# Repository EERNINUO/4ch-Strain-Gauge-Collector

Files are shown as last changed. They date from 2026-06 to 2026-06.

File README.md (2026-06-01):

<div align="center">

<!-- Assisted-by: DeepSeek - 文档框架 -->

# 4ch-Strain-Gauge-Collector

创新创业实践课程设计 E4 选题 – 4通道应变信号同步采集模块  
基于 STM32G473，内置 ADC + 高速 SRAM 缓冲 + USB 触发同步

<p align="center">
  <a href="https://github.com/EERNINUO/ArbWave30" style="margin: 2px;">
    
  </a>
  <a href="https://github.com/EERNINUO/ArbWave30" style="margin: 2px;">
    
  </a>
  <br/>
  <a href="https://raw.githubusercontent.com/EERNINUO/ArbWave30/main/LICENSE" style="margin: 2px;">
    
  </a>
  <a href="https://raw.githubusercontent.com/EERNINUO/ArbWave30/main/LICENSE" style="margin: 2px;">
    
  </a>
  <a href="https://raw.githubusercontent.com/EERNINUO/ArbWave30/main/LICENSE" style="margin: 2px;">
    
  </a>
</p>

</div>

---

## 📌 项目简介

本项目为《创新创业实践课程》课程 E4 选题的硬件与固件设计成果。  
设计基于 **STM32G473**（Arm Cortex-M4F）实现了 **4 通道应变信号同步采集**，支持外部事件触发、高速数据缓存（SRAM）及非易失参数存储（QSPI Flash），并通过 USB/串口实现与 PC 的命令交互与多模块同步。

设计周期：2 周（原理图 + PCB + 仿真 + 文档 + CubeMX工程，无实物焊接与固件代码）  
参考原型：NI‑9237 应变/桥输入模块

**核心指标**：
- 4 通道差分输入（±2.5V，共模 1.65V）
- 12 位内置 ADC，支持硬件过采样
- 4 阶有源低通滤波器（100kHz / 200kHz 可选）
- 最多 4 片 IS61WV204816BLL 高速 SRAM（2M×16bit）
- QSPI Flash 存储固件及标定参数
- USB 2.0 FS + 可线与串口（多模块同步触发）

## 🎯 主要特性

| 模块 | 特性 |
|---|---|
| **模拟前端** | 仪表放大器 (INA) + 1/4 衰减网络 + 4 阶 Sallen-Key 滤波器，净增益 1 |
| **ADC** | 内置 5 个独立 12 位 ADC，支持差分输入，事件触发同步采样 |
| **触发机制** | 片上比较器 (CMP) 整形外部触发信号，直接路由到定时器，响应延迟 < 1µs |
| **数据缓存** | FMC 总线扩展 SRAM（1~4 片），支持连续高速采集 |
| **存储** | QSPI Flash 用于程序 XIP 及标定参数掉电保存 |
| **通信** | USB CDC 虚拟串口 / 可线与硬件串口，支持多机同步 |

---

## 🖥️ 硬件架构概览

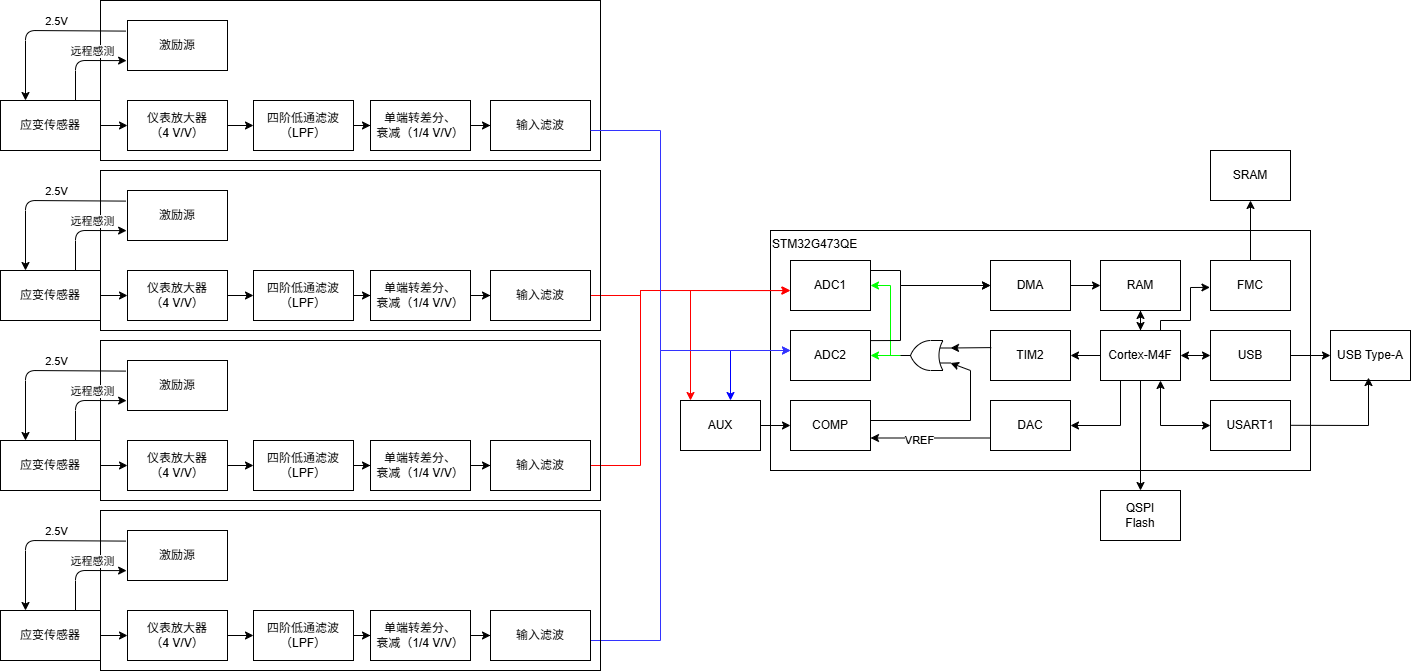
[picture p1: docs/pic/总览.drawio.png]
总览


详细原理框图及模块说明见 [硬件设计文档](docs/硬件设计文档.md)。

## 🛠️ 开发工具与环境

| 用途 | 工具 | 版本 |
|---|---|---|
| 原理图 & PCB |  KiCad | 10.0 |
| 模拟仿真 | LTspice  | 26.0.1 |
| MCU 配置 | STM32CubeMX | 6.13 |
| 代码生成 | Keil MDK | 5.36  |
| 版本管理 | Git + GitHub | - |

## 📁 仓库结构
4ch-Strain-Gauge-Collector/
├── docs/                     # 设计文档  
│   ├── pic/                  # 文档中用到的图片  
│   ├── hardware_design.md    # 硬件设计文档（原理图、PCB、BOM）  
│   └──  LICENSE              # CC BY-SA 4.0   
├── simulation/               # LTspice 仿真文件  
├── firmware/                 # CubeMX工程与生成代码（CubeMX + Keil）  
│   └── STM32G473.ioc         # CubeMX 配置文件  
├── hardware/                 # 硬件设计源文件  
|   ├── E4                    # Kicad 原理图与 PCB 文件  
│   └── LICENSE # CERN-OHL-S-2.0     
├── README.md                 # 项目说明  
└── LICENSE                   # GPL-3.0  

## 📜 许可证
Copyright © 2026 EERNINUO

本项目采用**多许可证策略**，不同部分适用不同许可证：

| 组成部分 | 许可证 |
|---|---|
| 固件 (MCU/FPGA 代码) | [GNU General Public License v3.0](LICENSE) |
| 硬件设计文件 (原理图、PCB、BOM) | [CERN Open Hardware Licence Version 2 - Strongly Reciprocal](hardware/LICENSE) |
| 文档、图片、README | [Creative Commons Attribution-ShareAlike 4.0 International](docs/LICENSE) |

这意味着：
- 你可以自由使用、修改、分享固件代码，但任何衍生代码也必须以 GPL-3.0 开源。
- 你可以基于硬件设计文件制作、分发物理设备，但必须同时开源你对设计文件的修改，并保留署名。
- 你可以复制和修改文档，但必须同样以 CC BY-SA 4.0 分享，并注明原作者。

## 📧 联系方式

如有问题或建议，请在 GitHub Issues 中提出。

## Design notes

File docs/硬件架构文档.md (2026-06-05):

<!------------------------------------------------------------------------
SPDX-License-Identifier: CC-BY-SA-4.0
Copyright (C) 2026 [EERNINUO](https://github.com/EERNINUO)

This work is licensed under the Creative Commons Attribution-ShareAlike 4.0 International License. 
To view a copy of this license, visit http://creativecommons.org/licenses/by-sa/4.0/.
------------------------------------------------------------------------->

<!-- Assisted-by: DeepSeek - 文档框架 -->

# E4 – 硬件架构文档

| 文档编号 | E4-HAD-001 | 版本 | V1.0 |
|---|---|---|---|
| 项目名称 | 创新创业实践课程设计 – E4 应变采集 | 日期 | 2026-05-28 |
| 起草人 | EERNINUO | 状态 | 设计中 |

## 1. 概述
E4 模块基于 **STM32G473** 实现 4 通道应变信号同步采集。外部应变片（半桥配置）输出的微弱差分信号经 **仪表放大器预放大 → 衰减匹配 → 4阶有源低通滤波** 后，送入 MCU 内置 ADC（12位，差分输入）。模块支持 **外部事件触发** 实现同步采集，采集数据通过 **USB 虚拟串口** 上传至 PC，并可选 **QSPI Flash** 存储标定参数、**SRAM** 缓存高速数据。

## 2. 系统框图
总览

## 3. 模块划分与功能定义

### 3.1 模拟前端（AFE）
| 级 | 功能 | 关键要求 | 增益(V/V) | 初步选型 |
|----|---|---|---|---|
| 0 | 应变片 | 激励电压 2.5V，差分输出 mV 级 | - | 350Ω 应变片 + 精密电阻 |
| 1 | 仪表放大器 | 共模抑制比 > 80dB，增益 4 倍 | 4 | INA828 |
| 2 | 4阶有源低通滤波器 | 截止频率 200kHz，巴特沃斯响应 | 1 | Sallen-Key (双二阶级联) |
| 3 | 衰减/单端转差分级 | 1/4 衰减，生成差分信号输入 ADC | 1/4 | 同相/反向放大器 |
| 4 | 输入滤波 | 截止频率 ≈ 1.5MHz，200kHz 衰减 < 0.1dB | 1 | 差分 RC 低通滤波 |
| 5 | ADC | 差分输入，共模 1.25V | ±2.5V（差分） | - | STM32G473 内置 ADC |

### 3.2 数字控制与采集（MCU）
- **型号**：STM32G473QE（128脚）
- **职责**：
  - 配置 2 个独立 ADC 实现 4 通道同步采样（其中 1、4；2、3  通道共用 1 个 ADC，采用双模式）
  - 电平触发采样（通过 MCU 内置比较器），启动采集序列，软件可设计预触发算法
  - 多功能串口触发采集，多机同步
  - 通过 USB（全速）与 PC 通信，实现虚拟串口数据上传
  - QSPI Flash（存储标定参数与程序）
  - 外部 SRAM（IS61WV204816BLL，最多 4 片，本设计选用 1 片）
  - 实现软件增益校准与偏移调零

### 3.3 触发与同步接口
- 电平触发：通过多路选择器选择触发源（CH1 ~ CH4），经 **比较器（内置 CMP）** 整形后触发定时器。
- 支持多模块同步：串口可线与（多模块共享触发总线）。

### 3.4 存储扩展
| 存储类型 | 型号 | 接口 | 容量 | 用途 |
|---|---|---|---|---|
| QSPI Flash | GD25Q32JV | QSPI | 32 Mbit | 程序存储 + 标定参数 |
| SRAM | IS61WV204816BLL | FMC | 2M×16bit | 高速采集数据缓存 |

### 3.5 电源系统
- 输入：DC 5V （DC 2.1mm 电源接口（或 USB 供电））
- 电源架构：
```mermaid
graph TD
    DC_5V -->|AMS1117-3.3V| 3.3V_D
    DC_5V -->|SGM3204| -5V_A
    DC_5V -->|TPS7A4701| 4V_A
    -5V_A -->|TPS7A3301| -4V_A
    4V_A -->|SGM2059| +3.3V_A
    V_REF -->|同相放大器（1/2 V/V）| 1.25V_V_COM[共模参考]
    4V_A -->|SGM2059| EXC_OUT[电桥激励电压（输出）]
    4V_A -->|SGM2059| 2.5V_EXC[2.5V 电桥激励电压]
```
## 4. 关键接口信号定义

| 接口 | 信号 | 方向 | 电平 | 说明 |
|---|---|---|---|---|
| 应变输入（4通道） | CHx_AI+, CHx_AI- | 输入 | 差分 ±2.5V max | 经调理后接 MCU ADC 差分输入 |
| 远程感测 | S+, S- | 输入 | < 2.5V | 可选，补偿线压降 |
| USB | USB_DP, USB_DM | 双向 | 3.3V | USB 全速，虚拟串口 |
| 外部触发 | TX/RX | 双向 | 3.3V/5V | UART 触发输入 |
| 调试接口 | SWDIO, SWCLK | 双向 | 3.3V | ST-Link 调试 |
| 电源输入 | V_IN | 输入 | 5V | DC 5V 电源输入 |

## 5. 物理与机械约束
- PCB 尺寸：110mm × 40mm × 170mm（模盒统一尺寸（内径））
- 连接器布局：USB、DC 2.1mm，开关位于板边、调试排针靠近MCU；4 通道应变输入端子集中布置
- 散热：主要功耗为 LDO，无需额外散热片

## 6. 下一步工作
- 详细原理图设计（仪表放大器、滤波器仿真）
- PCB Layout（重点关注模拟/数字分区、差分对等长）
- MCU CubeMX 配置与代码生成
- 设计报告撰写

## 7. 版本记录
| 版本 | 日期 | 修改内容 | 修改人 |
|---|---|---|---|
| V1.0 | 2026-05-29 | 初始版本 | EERNINUO |

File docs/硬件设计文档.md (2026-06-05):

<!------------------------------------------------------------------------
SPDX-License-Identifier: CC-BY-SA-4.0
Copyright (C) 2026 [EERNINUO](https://github.com/EERNINUO)

This work is licensed under the Creative Commons Attribution-ShareAlike 4.0 International License. 
To view a copy of this license, visit http://creativecommons.org/licenses/by-sa/4.0/.
------------------------------------------------------------------------->

<!-- Assisted-by: DeepSeek - 文档框架 -->

# E4 – 硬件设计文档

| 文档编号 | E4-HDD-001 | 版本 | V1.0 |
| ---| ---| ---- | ---- |
| 项目名称 | 创新创业实践课程设计 – E4 应变采集 | 日期 | 2026-05-28 |
| 起草人 | EERNINUO | 状态 | 设计中 |

## 1. 板卡概述
- 功能定位：4通道应变信号同步采集，经调理后由MCU内置ADC采集，通过USB上传。
- 关键性能指标：
  - 采样率：每通道最大 1 Msps（12位）
  - 输入范围：±10mV（应变满量程）→ 经 4 倍放大 → 1/4 衰减 → ±10mV 进入滤波器 → ADC 输入 ±2.5V
  - 滤波器截止频率：100kHz 或 200kHz（4阶巴特沃斯）
  - 触发响应延迟：< 1μs（硬件触发 + 中断）
- 主要接口：
  - 电源输入：USB Type-B (5V)
  - 数据接口：USB 虚拟串口
  - 调试接口：SWD (4-pin)
  - 外部触发：SMA 接口
  - 4 通道应变输入：端子排或 RJ-50（参考 NI-9237）

## 2. 模块详细设计

### 2.1 输入接口
- **功能描述**：接收来自应变片半桥的差分信号。
- **物理接口**：4 通道输入：RJ-45 接口（8针，4对差分）
- **引脚定义**

| 引脚 | 信号名 | 功能说明 |
|---|---|---|
| 1 | EX+ | 激励电压正 |
| 2 | EX- | 激励电压负 |
| 3 | RS+ | 远程感测电压正 |
| 4 | CH+ | 通道1正输入 |
| 5 | CH- | 通道1负输入 |
| 6 | RS- | 远程感测电压负 |
| 7 | EX- | 激励电压负 |
| 8 | EX+ | 激励电压正 |

### 2.2 模拟前端

#### 2.2.1 仪表放大器（预放大 4 倍）
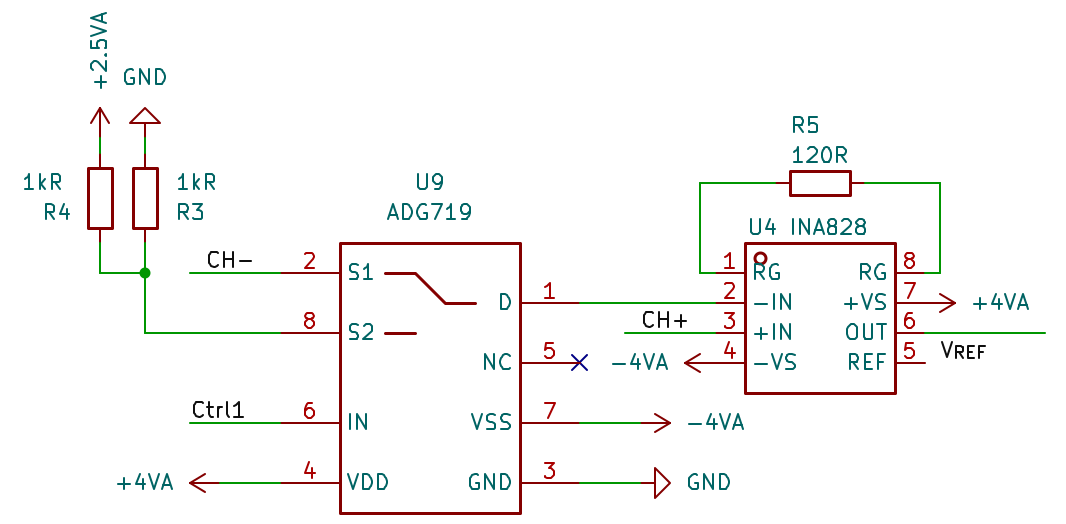
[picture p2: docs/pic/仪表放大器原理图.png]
仪表放大器
- **原理图截图**：
- **功能描述**：将应变片半桥的差分毫伏信号放大 4 倍，提高信噪比。
- **关键器件**：
  
| 器件 | 型号 | 特性 | 选型理由 |
|---|-----|---|---|
| 仪表放大器 | INA828 | 低噪声、高共模抑制比、可进行直流偏置 | 性能满足需求，可进行直流偏置 |
| 模拟开关 | ADG619 | 双电源、高开关速度、低导通电阻、低漏电流 | - |

- **设计计算**：
  - R_G计算：由数据手册可知：$G = 1 + \frac{50 k\Omega}{R_G}$，$G=4$，则 $R_G = \frac{50}{G - 1} \approx 16.7 k\Omega$
  - 输出信号：由数据手册可知 $V_O = G(V_{IN+} - V_{IN-}) + V_{REF}$，则输出电压 $V_O$ 的共模分量 $V_{DC} = V_{REF}$，差模分量 $V_{AC} = G(V_{IN+} - V_{IN-})$
- **接口信号**：
  | 信号名 | 方向 | 连接到 | 备注 |
  |--------|------|--------|------|
  | INA_IN+, INA_IN- | 输入 | 应变半桥输出 | 差分 |
  | INA_OUT | 输出 | 衰减级输入 | 单端 |
  | SW_Ctrl | 输入 | 桥路切换信号 | - |
  
- **仿真结果**：
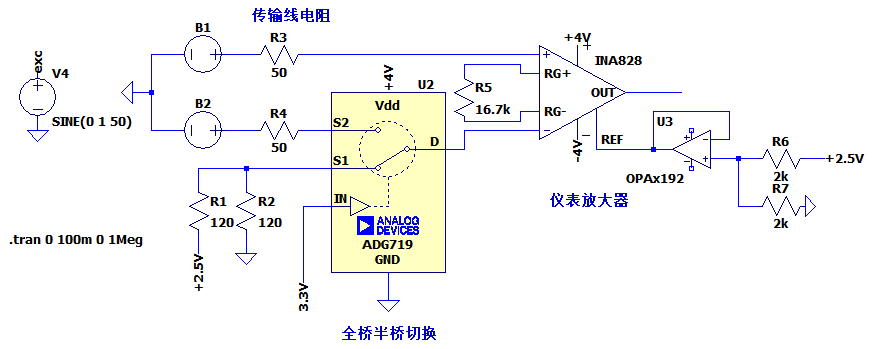
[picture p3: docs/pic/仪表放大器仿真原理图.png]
  
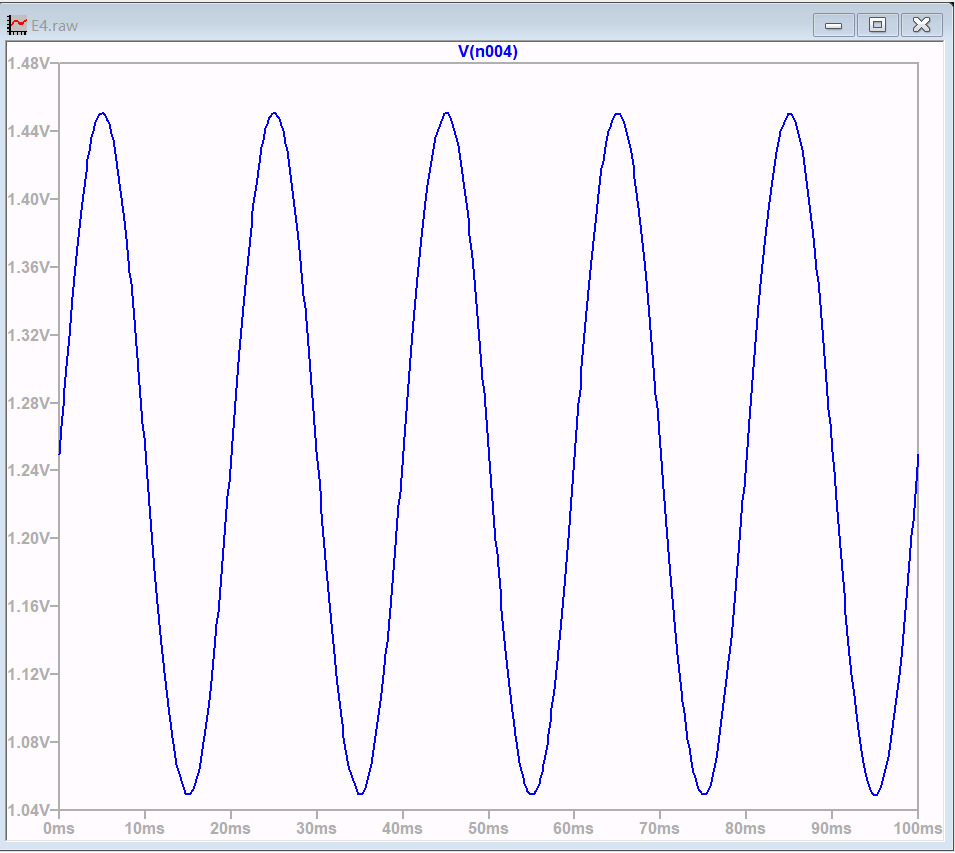
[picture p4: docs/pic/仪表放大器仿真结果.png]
  

- **测试点**：
  - TP_INA_OUT（测量放大后波形）

#### 2.2.2 4阶有源低通滤波器（100kHz/200kHz 可选）
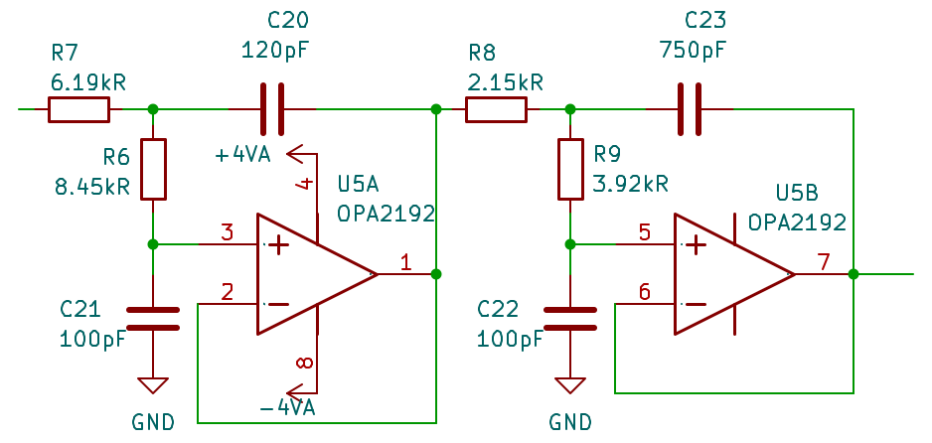
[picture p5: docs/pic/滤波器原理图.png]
滤波器原理图
- **原理图截图**：
- **功能描述**：四阶巴特沃斯低通滤波器，截止频率 200kHz，通带纹波 < 0.2dB。
- **关键器件**：

| 器件 | 型号 | 特性 | 选型理由 |
|---|-----|---|---|
| 运算放大器 | OPA2192 | 高增益、低噪声、低功耗 | - |
| 电阻 | - | 0.1% 精密电阻 | - |
| 电容 | - | 1% 精密电容，C0G/NP0 材质 | - |

- **设计计算**：
  通过 TI Filter Design Tool 计算得到滤波器参数，包括电阻和电容值。
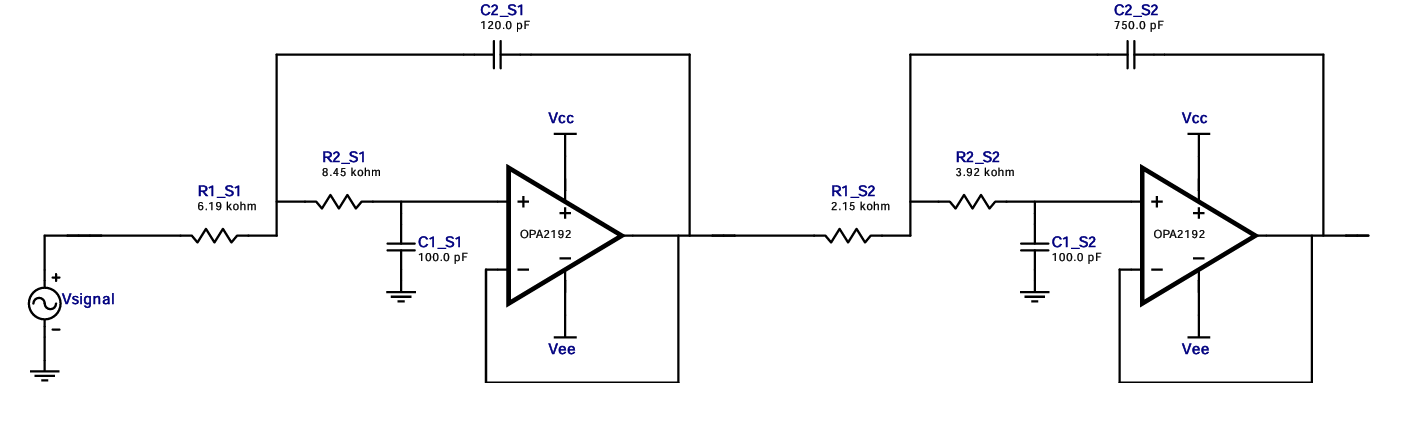
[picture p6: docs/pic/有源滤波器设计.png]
有源滤波器设计
  
- **仿真结果**：
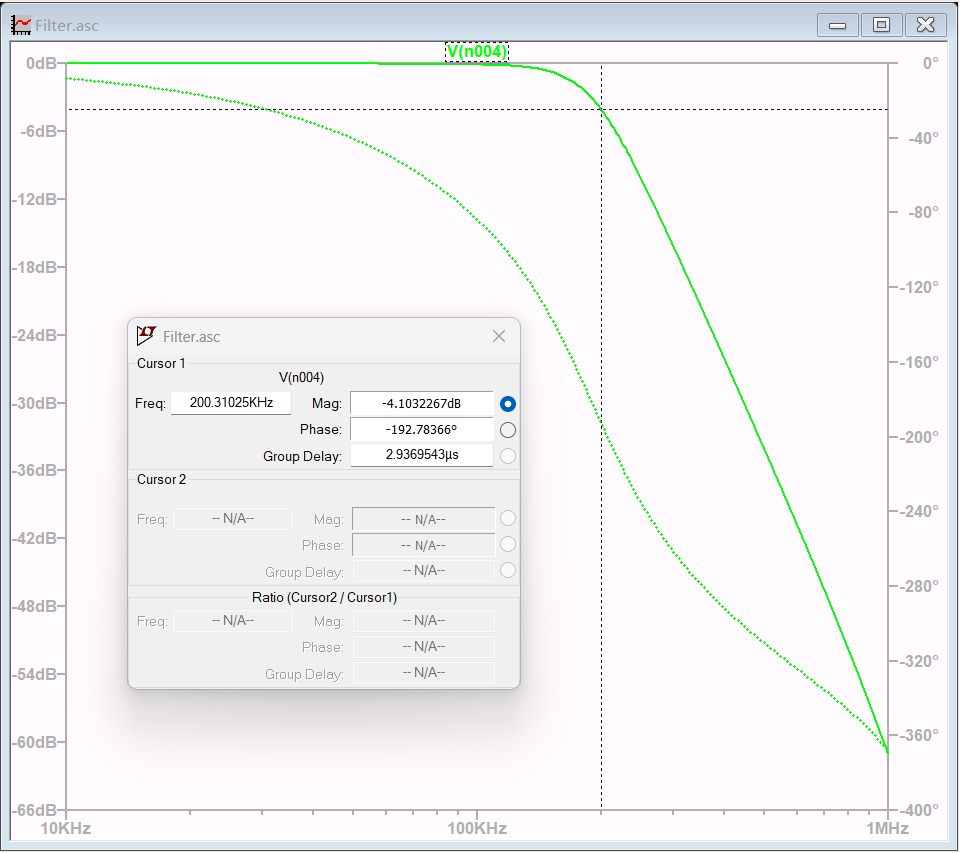
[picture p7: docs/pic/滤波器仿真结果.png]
滤波器仿真结果

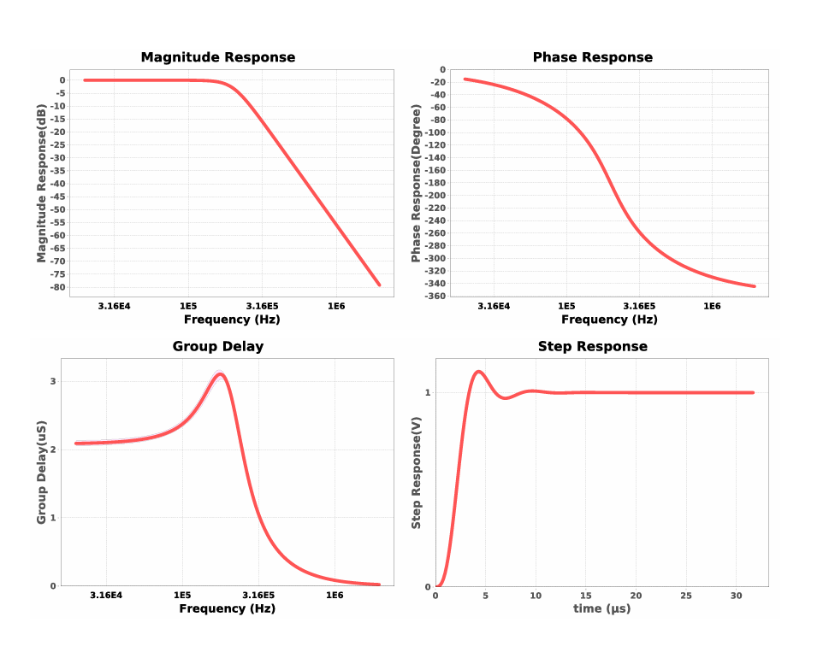
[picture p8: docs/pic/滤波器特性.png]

- **接口信号**：
- 
  | 信号名 | 方向 | 连接到 | 备注 |
  |--------|------|--------|------|
  | FILTER_IN | 输入 | 衰减级输出 | 单端 |
  | FILTER_OUT | 输出 | MCU ADC 输入（差分转换） | 需单端转差分 |
- **测试点**：
  - TP_FILTER_OUT（测量滤波器输出）

#### 2.2.3 差分转单端/衰减级
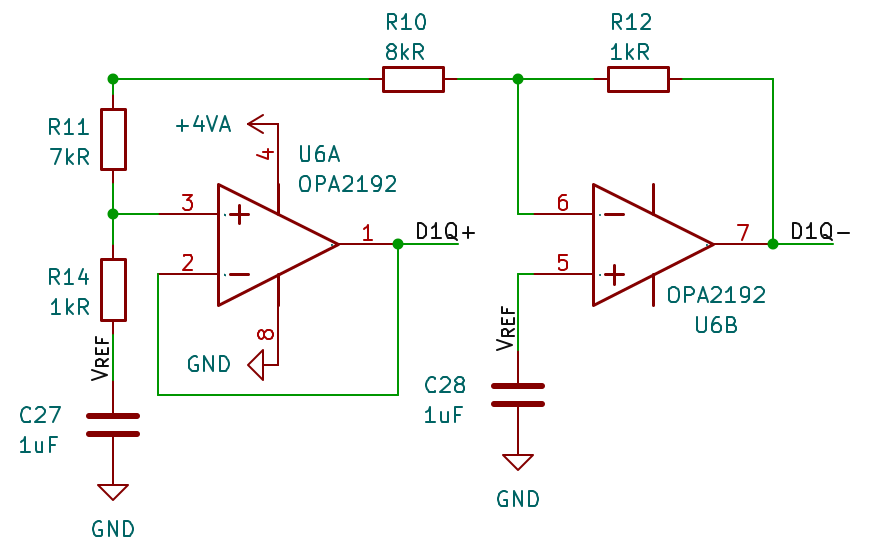
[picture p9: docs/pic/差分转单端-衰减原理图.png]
差分转单端-衰减原理图
- **原理图截图**：
- **功能描述**：将预放大后的信号衰减至适合 ADC 输入的差分信号与幅度。
- **关键器件**：
  
  | 器件 | 型号 | 特性 | 选型理由 |
  |------|-----|------|---------|
  | 运算放大器 | OPA2192 | 高增益、低噪声、低功耗 | - |
  | 电阻 | - | 0.1% 精密电阻 | - |
- **设计计算**：
设滤波器输出单端信号为 $V_{in}$，ADC要求的差分输入为 $V_{diff} = V_{in}/4$。为保持输出共模电平稳定在 $V_{cm}=1.65\text{V}$，令同相支路输出 $V_{out+} = V_{cm} + V_{in}/8$，反相支路输出 $V_{out-} = V_{cm} - V_{in}/8$。由此，差分输出 $V_{out+} - V_{out-} = V_{in}/4$，满足设计要求。
同相支路采用电阻分压加电压跟随器实现增益 $+1/8$；反相支路采用反相比例衰减器实现增益 $-1/8$。两路输出均以 $1.25\text{V}$ 为共模参考，由电阻分压网络从 $V_{REF}$ 电源获得。
- **仿真结果**：
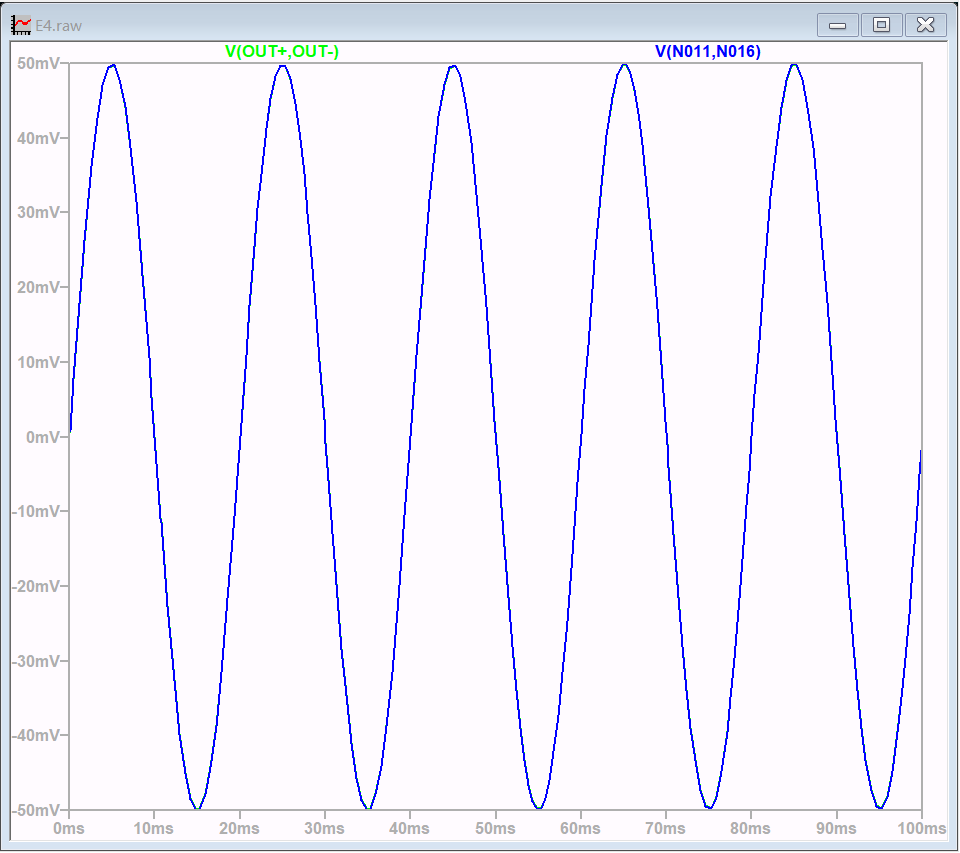
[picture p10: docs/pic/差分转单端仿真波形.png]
差分转单端仿真波形
  

#### 2.2.4 电平触发
- **原理图截图**：触发原理图
- **功能描述**：模拟开关选择要触发的信号，通过片内比较器实现电平触发，触发信号直接连接到定时器。
- **关键器件**：
  
  | 器件 | 型号 | 特性 | 选型理由 |
  |------|-----|------|---------|
  | 模拟开关 | ADG704 | 双电源、高开关速度、低导通电阻、低漏电流 | - |

### 2.2 MCU 最小系统（STM32G473）
- **原理图截图**：MCU
- **功能描述**：核心控制与数据采集。
- **关键器件**：STM32G473VE，8MHz 晶振，复位电路，SWD 接口。

| 器件 | 型号 | 特性 | 选型理由 |
|---|-----|---|---|
| MCU | STM32G473QET6 | ARM Cortex-M4F, 512KB Flash, 128KB RAM，丰富的模拟外设 | 性能满足需求，成本合理 |

- **具体设计**：
  - 电源：VDD 各引脚就近 100nF 电容，VDDA 独立 1μF+100nF。
  - 时钟：HSE 24MHz 晶振（10pF 负载电容）。
  - 调试接口：SWD（SWCLK, SWDIO） + NRST。
  - BOOT0 通过 10k 下拉，按键上拉可选。
  - UART：TX 经过开漏缓冲器接入总线；RX 上拉到 3.3V。
  
- **接口信号**：

| 接口名 | 方向 | 协议 | 连接到 | 备注 |
|---|---|---|---|---|
| USB | 双向 | USB 2.0 FS | USB Type-A | CDC；差分信号，90Ω 阻抗 |
| GPIO | 输出 | GPIO | 模拟开关 | 全桥-半桥切换 |
| UART | 双向 | UART(115200) | USB Type-A | 外部触发，多机同步 |
| QSPI | 双向 | QSPI | Flash | 存储程序与校准参数 |
| FMC | 双向 | FMC  | SRAM | 高速数据缓存 |
| ADC | 输入 | ADC | 模拟前端输出 | 4通道差分输入 |
| CMP | 输入 | 内置比较器 | 多路选择器输出 | 电平触发 |

### 2.3 USB 接口
- **原理图截图**：USB
- **功能描述**：虚拟串口（CDC）通信。
- **关键器件**：

| 器件 | 型号 | 特性 | 选型理由 |
|---|-----|---|---|
| USB 接口 | 双层 USB Type-A | 4线母头 USB2.0 | 连接稳定，可靠性高，行业标准 |
| ESD 芯片 | PRTR5V0U2X | 超低电容双轨对轨ESD芯片 | 保护USB接口 |

- **保护设计**：ESD 保护，VBUS 分压后接 MCU GPIO 用于检测连接。
  - ESD 保护：USB DP/DM/VBUS 经过 PRTR5V0U2X，靠近接口放置。
  - VBUS 检测：通过 20k/39k 分压接入 MCU GPIO，检测 USB 连接状态。

### 2.4 外部触发输入
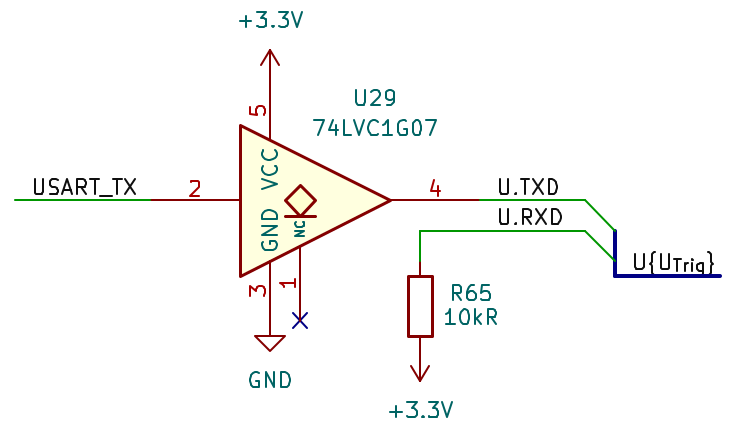
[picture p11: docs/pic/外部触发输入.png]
外部触发输入
- **原理图截图**：
- **功能描述**：接收外部串口触发命令，启动数据采集。也可发送同步指令
- **关键器件**：
  | 器件 | 型号 | 特性 | 选型理由 |
  |------|-----|------|---------|
  | 开漏缓冲器 | 74LVC1G07 | 低功耗，高速度 | - |

### 2.5 存储扩展
#### 2.5.1 QSPI Flash
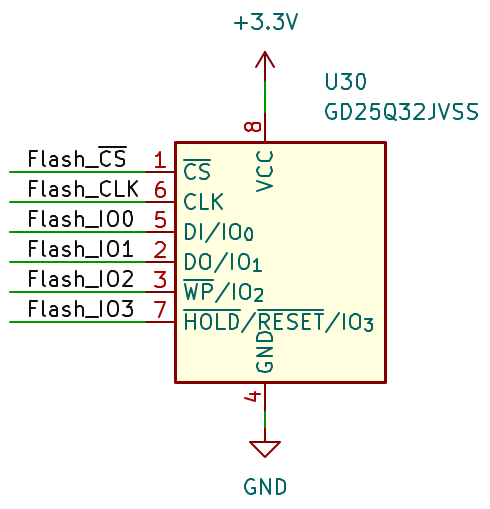
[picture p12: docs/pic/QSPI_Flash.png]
QSPI_Flash
- **原理图截图**：
- **功能描述**：存储程序（通过 QSPI 执行）和标定参数。
- **关键器件**：
  | 器件 | 型号 | 特性 | 选型理由 |
  |------|-----|------|---------|
  | Flash | GD25Q32 | 32Mbit SPI Flash | - |

#### 2.5.2 SRAM（1片 IS61WV204816BLL）
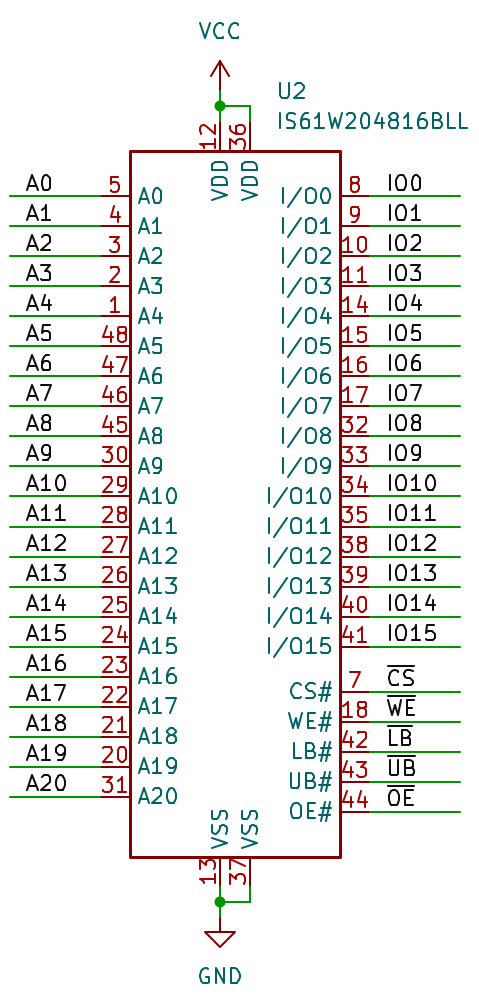
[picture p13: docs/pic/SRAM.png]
SRAM
- **原理图截图**：
- **功能描述**：扩展数据缓存，用于高速采集。
- **具体设计**：
  FMC 驱动，地址线 A0-A20，数据线 D0-D15，控制线 WE, OE, CE。
- **PCB 注意**：
  地址/数据线等长（误差 < 50mil），去耦电容靠近芯片。

### 2.6 电源与去耦
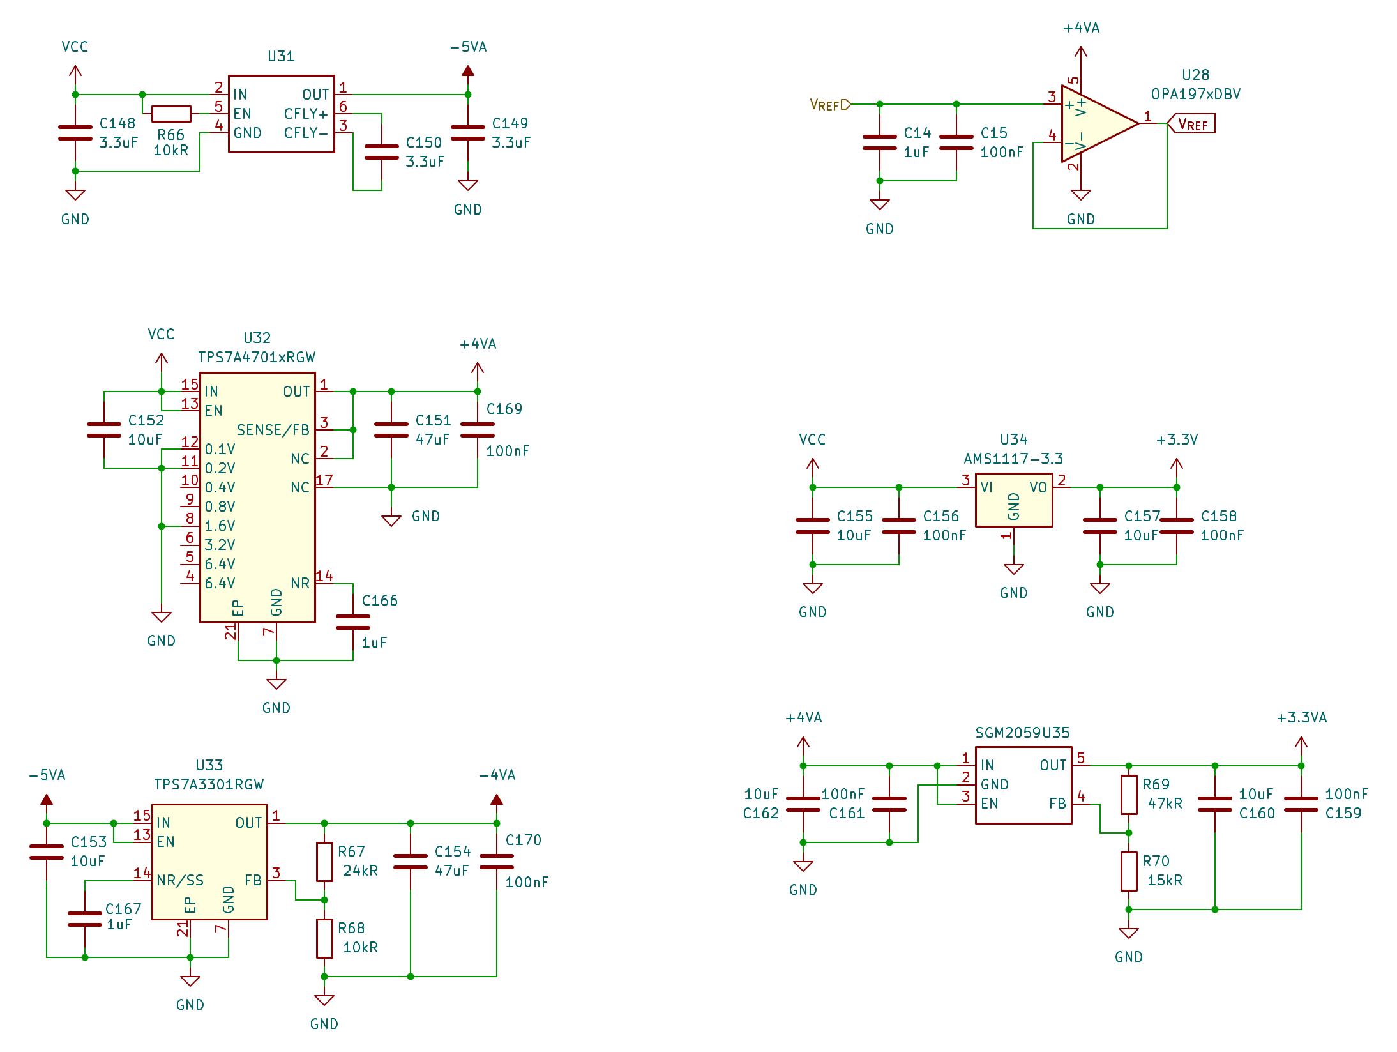
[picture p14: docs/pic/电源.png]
电源
- **原理图截图**：
- **功能描述**：为各模块提供稳定电源。
- **关键器件**：
  
  | 电压 | 型号 | 理由 |
  |------|------|------|
  | -5V_A | SGM3204 | 负电压转换，低纹波，适合模拟电路 |
  | 4V_A | TPS7A4701 | 超低噪声，适合模拟电路 |
  | -4V_A | TPS7A3301 | 负电压 LDO，低噪声 |
  | 3.3V_D | AMS1117-3.3 | 成本低，数字部分够用 |
  | 3.3V_A | SGM2059 | 低噪声，国产芯片价格低，供应链稳定 |
  | 2.5V 激励 | SGM2059 | 低噪声，国产芯片价格低，供应链稳定 |
  | 1.25V 参考 | 电阻分压+运放缓冲 | 共模电压 |

## 3. PCB 布局与布线指南

### 3.1 层叠结构
- 层数：4 层
  - Top：信号 + 局部电源
  - Inner1：完整地平面（GND）
  - Inner2：电源分割（3.3V_D, 3.3V_A，±4V_A, 1.8V_A, 2.5V）
  - Bottom：信号 + 地铜
> 此处采用四层板是因为题目要求使用四层板进行设计，但考虑到 SRAM 的布线复杂度及高速下参考平面的切换问题，实际设计中推荐采用六层板或更多

### 3.2 整体布局原则
1. 按功能分区：模拟前端（左） → MCU（中） → 接口（右），符合信号流向。
2. 模拟区与数字区物理隔离，地平面不分割。
3. 电源转换（LDO）靠近输入接口，输出电容紧贴 LDO。
4. 晶振靠近 MCU，下方不走线。

### 3.3 关键模块布线约束

| 模块 | 约束 | 
|---|---|
| 模拟差分信号（传感器输入、ADC 差分输入） | 等长、紧耦合，阻抗 100Ω，周围包地 |
| USB DP/DM | 90Ω 差分阻抗，等长误差 < 1mm |
| QSPI 四线 | 各自长度匹配（误差 < 5mm） |
| SRAM 地址/数据 | 组内等长误差 < 100mil，组间等长误差 < 300mil ，组间保持间距 |
| SRAM 控制线 | 等长，紧耦合，阻抗 100Ω，周围包地 |
| 触发输入 | 走线短，远离高频数字信号 |
| 电源 | 模拟 3.3V 与数字 3.3V 单点连接（0Ω 电阻或磁珠） |
> ST 应用笔记指出，在 FMC 走线长度 < 120mm 时，可以不考虑阻抗匹配与端接。

### 3.4 地平面与电源完整性
- 完整地平面（Inner1），所有信号参考该层。
- 模拟电源区域在内层分割，与数字电源层分开，但在输入端通过磁珠单点汇合。
- 每个 IC 电源引脚放置 0.1μF 电容，大电容（10μF）分布于电源入口及 SRAM 附近。

### 3.5 测试点设计
- 各电压轨（3.3V_D, 3.3V_A, 1.8V_A, 2.5V, 1.25V等）
- 关键模拟节点（INA_OUT, FILTER_OUT, D1Q±）
- 关键数字信号（USB，UART，QSPI）
- 测试点形式：直径 1mm 圆形露铜，加过孔。

## 4. 测试与调试计划

### 4.1 上电前检查
- 电源对地短路测试
- 极性检查（电容、二极管、LDO）
- 焊接完整性（尤其 QFN 封装）

### 4.2 分步调试
1. **电源**：焊好 LDO 后测各电压轨空载纹波。
2. **MCU 最小系统**：焊 MCU、晶振、复位、SWD，烧录点灯代码。
3. **存储**：测试 QSPI Flash 读写，SRAM 读写。
4. **USB**：枚举虚拟串口，回环测试。
5. **触发**：输入脉冲，MCU 中断响应。
6. **模拟前端**：输入已知直流电压，逐级测量放大器输出，验证增益与滤波。
7. **全链路**：输入模拟应变信号（函数发生器 + 电阻分压模拟电桥），采集数据上传，验证线性度。

### 4.3 关键波形测试点
- 滤波截止频率（扫频输入，测输出 -3dB 点）
- ADC 采样抖动（固定直流，观察码值跳动）
- 触发延迟（示波器同时测触发输入和 ADC 采样完成信号）

## 5. 元器件清单（BOM 摘要）

| 位号 | 型号 | 数量 | 单价 | 总价 |
|---|---|---|---|---|
| U1 | STM32G473VE | 1 | 45.00 | 45.00 |
| U2 | AD8422 | 4 | 28.00 | 112.00 |
| U3 | OPA2374 | 2 | 8.00 | 16.00 |
| U4 | TPS7A4701 | 1 | 22.00 | 22.00 |
| ... | ... | ... | ... | ... |
| **总计** | | | | **< 300元** |

（完整 BOM 另附 CSV）

## 7. 版本记录
| 版本 | 日期 | 修改内容 | 修改人 |
|---|---|---|---|
| V1.0 | 2026-06-03 | 初始版本 | EERNINUO |

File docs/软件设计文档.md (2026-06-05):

<!------------------------------------------------------------------------
SPDX-License-Identifier: CC-BY-SA-4.0
Copyright (C) 2026 [EERNINUO](https://github.com/EERNINUO)

This work is licensed under the Creative Commons Attribution-ShareAlike 4.0 International License. 
To view a copy of this license, visit http://creativecommons.org/licenses/by-sa/4.0/.
------------------------------------------------------------------------->

<!-- Assisted-by: DeepSeek - 文档框架 -->

# E4 – 4通道应变信号采集模块软件设计文档

| 文档编号 | E4-SDD-001 | 版本 | V1.0  |
| ---| --- | ---- | ----- |
| 项目名称 | 课程设计 E4 应变采集 | 日期 | 2026-06-04 |
| 起草人 | EERNINUO | 状态 | 设计中 |

## 1. 软件总体架构

### 1.1 设计思路
本模块软件基于 **FreeRTOS** 实时操作系统，充分利用 STM32G473 的多任务处理能力及硬件外设，实现以下功能：

- **4 通道 ADC 同步采集**：使用 MCU 的 2 个独立 ADC 模块（ADC1, ADC2），将 4 路应变信号按通道配对分配：**ADC1 负责 CH1 和 CH4，ADC2 负责 CH2 和 CH3**（具体 ADC 输入引脚号需根据原理图确认，见 §2.2），配置为 **双 ADC 同步模式**（dual regular simultaneous mode），由 TIM1 的 TRGO 硬件触发信号同步启动转换，DMA 循环搬运数据至缓冲区。
- **硬件触发链**：外部触发信号经模拟开关（ADG704）选择后送入 MCU **内置比较器（CMP）** 整形，比较器输出直接路由至定时器（TIM1）的从模式触发输入（slave mode trigger），定时器产生 TRGO 信号同步启动 ADC1+ADC2 转换。**全程硬件链路，无需 CPU 中断干预启动**，触发响应延迟 < 1μs。
- **数据缓存与上传**：
  - 采集数据通过 **USB 虚拟串口（CDC）** 实时上传至 PC（SCPI 协议简化版）。
  - 高速采集数据暂存于 **外部 SRAM（IS61WV204816BLL，FMC 接口，4MB）**，支持"采集→缓存→批量上传"模式，突破 MCU 内部 RAM（128KB）限制。
- **系统配置与标定**：QSPI Flash（GD25Q32JV，32Mbit）中存储通道增益系数、偏置校准值及程序代码（支持 XIP 执行），上电时读取并应用于采集数据。
- **多机同步**：通过开漏缓冲器（74LVC1G07）线与的 UART 总线实现多模块同步触发信号共享，任一模块发出触发命令均可同步启动所有模块采集。

### 1.2 FreeRTOS 任务设计

| 任务名称 | 优先级 | 栈大小 (字) | 功能描述 | 触发方式 |
|---|---|---|---|---|
| `vADC_Task` | 最高 (3) | 512 | 初始化 ADC 触发链（CMP→TIM→ADC），等待 DMA 半满/全满中断信号量，对原始 ADC 数据做增益/偏置校正后打包为 `adc_data_t` 发送至队列 | 二值信号量（来自 DMA 传输完成中断回调） |
| `vUSB_Task` | 中等 (2) | 512 | 从队列接收数据，通过 USB CDC 发送至 PC | 队列消息（队列非空） |
| `vSRAM_Task` | 中等 (2) | 512 | 从队列接收数据，写入外部 SRAM（FMC 接口）环形缓冲区；在"批量上传"模式下将 SRAM 中的数据经 USB 上传 | 队列消息 + 缓存水位标志 |
| `vUART_Sync_Task` | 较高 (3) | 256 | 监听 UART 总线上的同步触发帧；收到外部同步帧时向本地触发链发出启动信号；本地产生触发时向总线广播同步帧 | UART RX 中断 + 软件事件标志 |
| `vMonitor_Task` | 最低 (1) | 256 | 监控系统状态（LED 闪烁、队列水位、SRAM 缓存占用、错误标志） | 软件定时器（每 500ms） |

> **注**：队列传递的数据结构为 `struct adc_data_t`，包含 4 通道原始值（uint16_t[4]）、时间戳（uint32_t，来自 TIM 计数器）、触发序号（uint32_t）、采集模式标志（uint8_t）。

### 1.3 系统流程图（Mermaid）

```mermaid
graph TD
    A[系统上电] --> B[硬件初始化: 时钟, GPIO, ADC, DMA, USB, FMC-SRAM, QSPI, CMP, TIM]
    B --> C[读取 QSPI Flash 标定参数]
    C --> D[创建 FreeRTOS 队列与信号量]
    D --> E[创建 vADC_Task, vUSB_Task, vSRAM_Task, vUART_Sync_Task, vMonitor_Task]
    E --> F[启动 FreeRTOS 调度器]

    subgraph 硬件触发链
        T0[外部触发信号] --> T1[模拟开关 ADG704 选源]
        T1 --> T2[CMP 比较器整形]
        T2 --> T3[TIM1 从模式触发输入]
        T3 --> T4[TIM1 TRGO]
        T4 --> T5[ADC1+ADC2 同步转换]
        T5 --> T6[DMA 搬运至缓冲区]
        T6 --> T7[DMA 传输完成中断]
    end

    subgraph vADC_Task
        F1[等待 DMA 中断信号量] --> F2[读取 ADC1/ADC2 DMA 缓冲区]
        F2 --> F3[增益/偏置校正 → 组合4通道数据]
        F3 --> F4[封装 adc_data_t 发送至队列]
        F4 --> F1
    end

    subgraph vUSB_Task
        U1[等待队列消息] --> U2[获取 adc_data_t]
        U2 --> U3[格式化字符串(SCPI 风格)]
        U3 --> U4[USB CDC 发送]
        U4 --> U1
    end

    subgraph vSRAM_Task
        S1[等待队列消息] --> S2[写入 FMC SRAM 环形缓冲区]
        S2 --> S3{缓存水位 ≥ 阈值?}
        S3 -- 是 --> S4[触发"批量上传"模式：从 SRAM 读取数据经 USB 发送]
        S4 --> S1
        S3 -- 否 --> S1
    end

    subgraph vUART_Sync_Task
        Y1[等待 UART RX 中断事件] --> Y2{判断帧类型}
        Y2 -- 同步触发帧 --> Y3[向本地触发链发出触发信号]
        Y3 --> Y1
        Y2 -- 其他命令 --> Y4[解析并执行]
        Y4 --> Y1
    end

    subgraph vMonitor_Task
        M1[延时 500ms] --> M2[翻转 LED]
        M2 --> M3[检查队列溢出/SRAM 缓存满/任务挂起]
        M3 --> M1
    end
```

## 2. CubeMX 配置要点

> 以下配置基于 **STM32CubeMX 6.12** 及 **STM32G473VE**。

### 2.1 时钟树配置

| 参数 | 值 | 说明 |
|---|-----|---|
| HSE | 24 MHz (外部晶振) | 硬件设计文档指定 24MHz，10pF 负载电容 |
| PLL 源 | HSE |  |
| PLLM | 2 | 分频至 12MHz (24/2) |
| PLLN | 24 | 倍频至 288MHz (12×24) |
| PLLP | 2 | 主 PLL 分频（系统时钟 = 288/2 = 144MHz） |
| PLLQ | 6 | USB 分频：288/6 = 48MHz |
| 系统时钟 (SYSCLK) | 144 MHz | 最大 170MHz，留余量 |
| AHB 预分频 (HCLK) | /1 | 144 MHz |
| APB1 (PCLK1, 含定时器) | /1 → 144 MHz | G4 的 APB1 最高支持 170MHz，144MHz 无需分频 |
| APB2 (PCLK2, 含 ADC) | /1 → 144 MHz | ADC 内核时钟由 APB2 经 ADC 内部预分频器得到 |

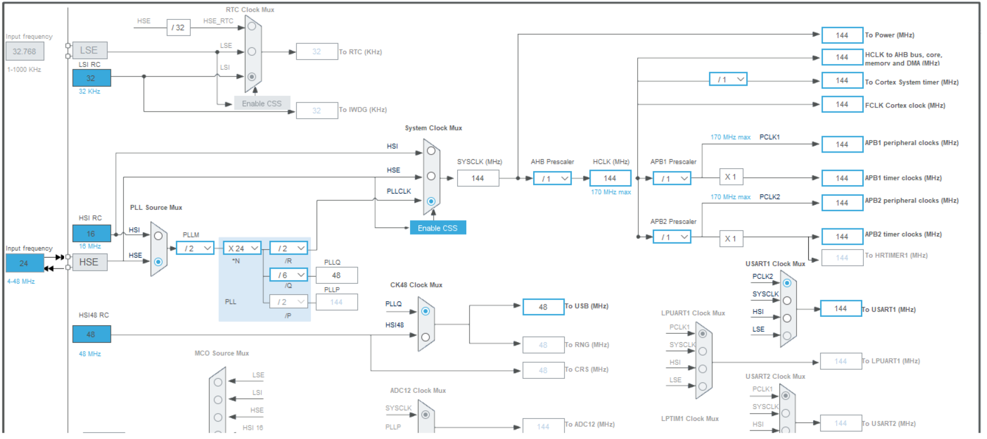
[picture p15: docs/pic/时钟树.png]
时钟树


### 2.2 ADC 配置（双 ADC 同步规则模式 + 双重交错模式）

STM32G473 内部集成 **5 个独立 ADC**，本设计使用其中的 **ADC1 和 ADC2** 实现 4 通道同步差分采集。

**通道分配**：

- **ADC1**：负责 **CH1 和 CH4**（各为一组差分对）
- **ADC2**：负责 **CH2 和 CH3**（各为一组差分对）

| 参数 | ADC1 | ADC2 | 说明 |
|---|---|---|---|
| 模式 | **双 ADC 常规同步模式** (Dual regular simultaneous mode) | 同一 TRGO 信号同步触发 |
| 分辨率 | 12 位 | 12 位 |  |
| 数据对齐 | 右对齐 | 右对齐 |  |
| 扫描方向 | 使能扫描 | 使能扫描 | 每个 ADC 依次转换 2 个通道 |
| 差分通道 | CH1(IN6+/IN6-), CH4(IN11+/IN11-) | CH2(IN8+/IN8-), CH3(IN1+/IN1-) | - |
| 采样时间 | 12.5 个 ADC 时钟周期 | 12.5 个 ADC 时钟周期 | 适应 ≤ 200kHz 信号带宽 |
| 触发源 | **TIM1_TRGO** | **TIM1_TRGO** | **同一 TRGO 信号同步触发** |
| DMA 请求 | 使能 (循环模式) | 使能 (循环模式) | 搬运至独立缓冲区 |

> **关键点**：
> - ADC1 和 ADC2 在 CubeMX 中配置为 **"Dual regular simultaneous mode"**（在 ADC1 的 Parameter Settings → ADC_Regular_Sequence → Mode 中选择）。
> - 每次 TIM1_TRGO 触发后，两个 ADC **同时**启动各自通道的规则序列转换。
> - DMA 将结果分别搬运至 `adc1_buf[2]`（存放 CH1, CH4 原始值）和 `adc2_buf[2]`（存放 CH2, CH3 原始值）。
> - DMA 传输完成中断中释放信号量，通知 vADC_Task 处理数据。

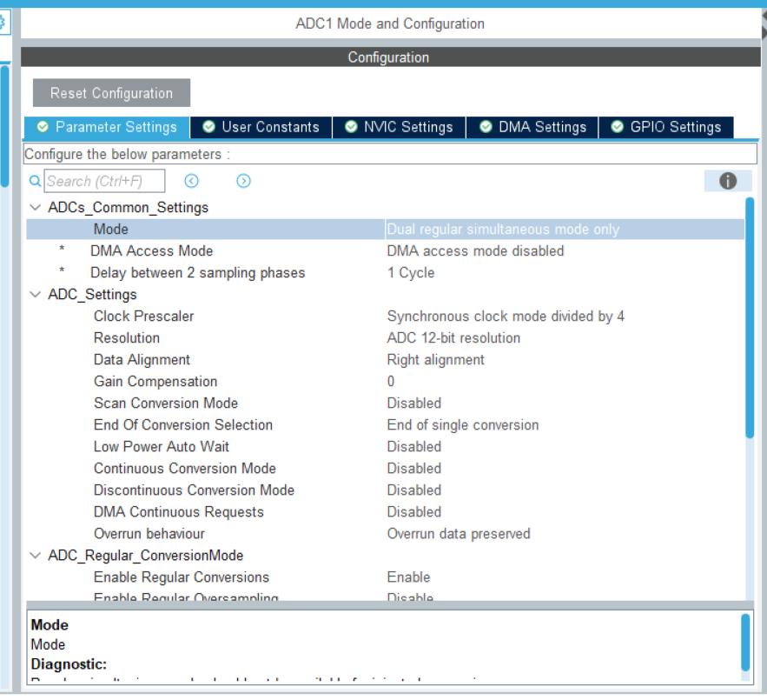
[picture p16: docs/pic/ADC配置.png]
ADC配置


### 2.3 DMA 配置

| 通道 | 外设 | 方向 | 数据宽度 | 模式 | 优先级 | 缓冲区大小 |
|---|---|---|---|---|---|---|
| DMA1_Channel1 | ADC1 | 外设到内存 | Half Word (16-bit) | 循环 | 高 | `adc1_buf[2]` (2×16bit × N 缓冲区) |
| DMA1_Channel2 | ADC2 | 外设到内存 | Half Word (16-bit) | 循环 | 高 | `adc2_buf[2]` (2×16bit × N 缓冲区) |

> **双缓冲设计**：
> - 建议使用 **DMA 双缓冲区模式** (Double Buffer Mode，由 CubeMX 的 DMA Transfer Mode 中勾选) 或使用 **DMA 半满/全满中断** 实现 ping-pong 缓冲。
> - 缓冲区大小建议设为 256~512 个采样点（每通道），即 `adc1_buf[2][512]`、`adc2_buf[2][512]`，配合 DMA 循环模式使用。
> - **中断处理原则**：DMA 中断 ISR 中**只做信号量释放**，不做数据处理（遵循 FreeRTOS 中断安全规范），实际数据组合在 vADC_Task 中完成。

### 2.4 定时器 TIM1 配置（触发源与硬件触发链）

TIM1 在本设计中扮演 **触发链核心** 角色：接收 CMP 比较器输出作为从模式触发输入，产生 TRGO 信号同时启动 ADC1+ADC2 同步转换。

**完整触发链路（全硬件链路，无 CPU 干预启动延迟）：**

```
外部 SMA → 模拟开关 ADG704(选择通道) → COMP6(内置比较器，整形) → TIM1 从模式触发输入(TI1_FP1 或 TI2_FP2)
    → TIM1 TRGO (UEV) → ADC1+ADC2 同步转换 → DMA 搬运 → DMA 完成中断(释放信号量→通知 vADC_Task)
```

**CMP 比较器配置要点**（需在 CubeMX 的 Analog → COMP6 中配置）：

| 参数 | 值 | 说明 |
|---|-----|---|
| 模式 | 比较器模式 | 输入：外部触发信号（经模拟开关选择），参考：内部 DAC 或外部 Vref |
| 正输入 (INP) | GPIO（连接 ADG704 输出引脚） | 需根据原理图确认具体 GPIO |
| 负输入 (INM) | VREFINT (内部参考) 或 DAC1_OUT | 用于设置触发电平阈值 |
| 输出极性 | 不反向 |  |
| 迟滞 | 无或小迟滞 | 根据触发信号质量调整 |
| 输出重定向 | **TIM1 输入捕获通道** | 连接至 TIM1 的 TI1 (ITR) 或 TI2，使 TIM1 能从模式触发 |
| BLG 输出 | 使能 | 产生中断标志（可选，用于调试） |

**TIM1 定时器配置：**

| 参数 | 值 | 说明 |
|---|-----|---|
| 时钟源 | 内部时钟 (144MHz, PCLK1) | APB1 = 144MHz（不分频），定时器使用 PCLK1 直接作为计数时钟 |
| 从模式 | **触发模式 (Trigger mode)** | CMP 输出作为触发源 |
| 触发源选择 | **ITR0 → COMP6_OUT** | STM32G473 中 COMP6_OUT 内部连接到 TIM1 的 ITR0，具体见 RM0440 Table |
| 主模式输出 (TRGO) | **更新事件 (UEV)** | 连接到 ADC 的触发输入 |
| 预分频器 (PSC) | 144-1 | 计数时钟降至 1MHz（用于周期性模式时） |
| 自动重载 (ARR) | 可变（如 10000） | 周期性模式下产生 100Hz 触发 |
| 计数器模式 | 向上计数 |  |
| 自动重载预装载 | 使能 |  |

> **关于两种采集模式的软件切换**：
>
> | 模式 | TIM1 从模式配置 | 触发源 | 适用场景 |
> |------|---------------|--------|----------|
> | **外部触发模式**（默认） | 触发模式 (SMS=110)，等待 CMP 输入 | CMP 输出（外部信号） | 瞬态信号捕捉、多机同步 |
> | **周期性采集模式** | 关闭从模式 (SMS=000)，使用内部计数 | 内部 UEV 自动触发 | 连续监测、无外部触发源 |
>
> 切换方式：操作 `TIM1->SMCR` 寄存器的 SMS 位域，以及 `TIM1->CR1` 的 CEN 位。建议在 vUART_Sync_Task 中根据接收到的命令（如 `:TRIG:SOURCE EXT` 或 `:TRIG:SOURCE INT`）进行切换。

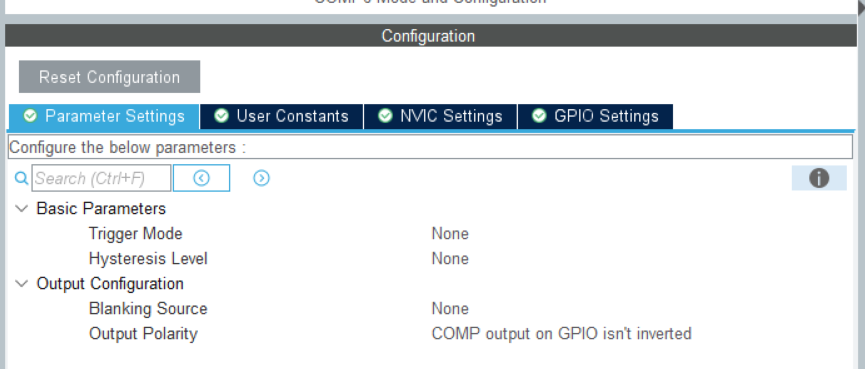
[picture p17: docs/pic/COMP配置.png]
COMP配置

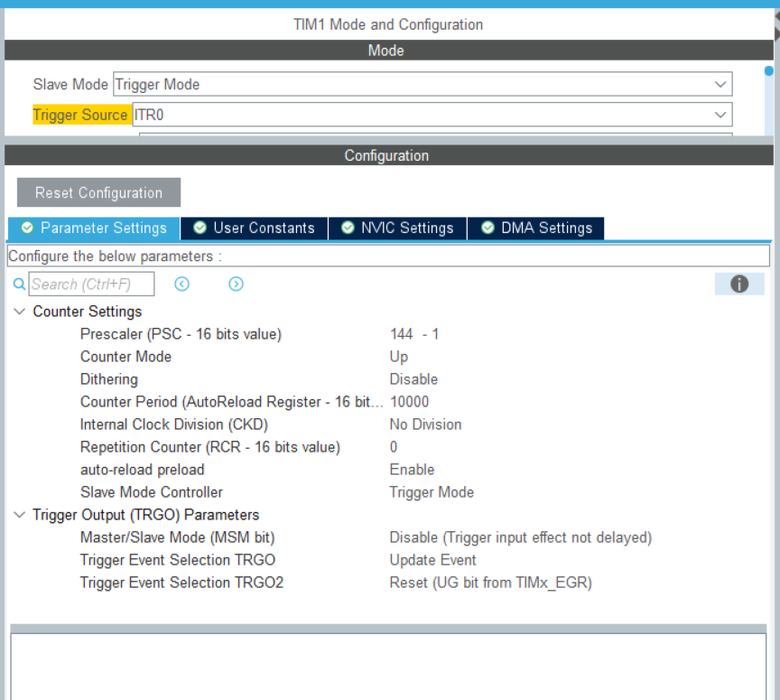
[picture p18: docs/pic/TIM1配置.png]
TIM1配置


### 2.5 USB 外设配置

| 参数 | 值 | 说明 |
|---|-----|---|
| 设备模式 | Communication Device Class (CDC) | 虚拟串口 |
| 端点 | EP1 IN (64 bytes), EP2 OUT (64 bytes) | 中断传输 |
| 时钟 | 48 MHz (从 PLLQ 输出) | 必须精确 |
| 缓冲区 | 用户定义 |  |

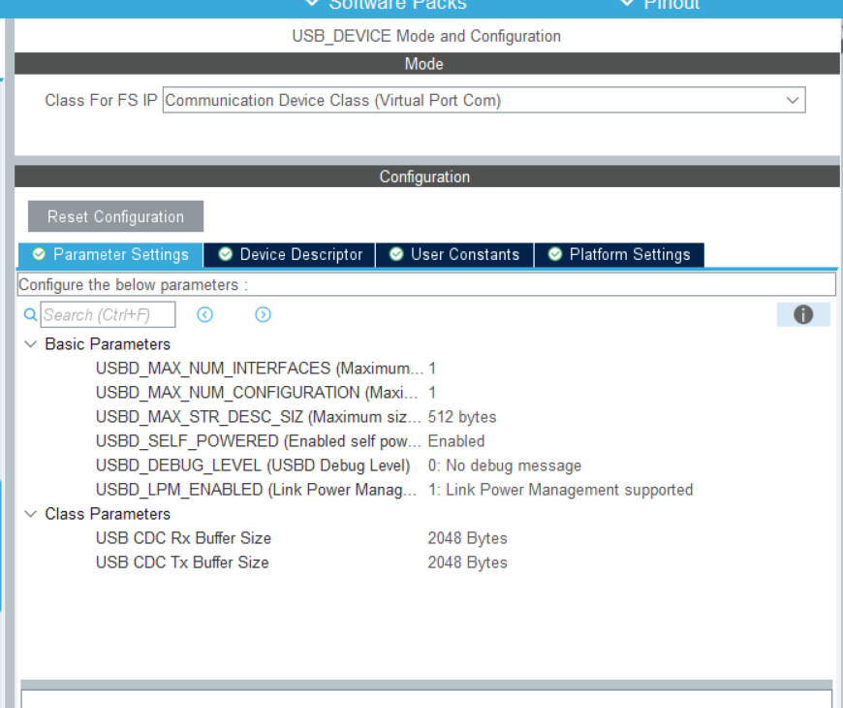
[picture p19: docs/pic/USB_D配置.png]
USB配置


### 2.6 QSPI 配置（标定参数存储）

| 参数 | 值 | 说明 |
|---|-----|---|
| 模式 | **QSPI (4 线)** | 硬件设计使用 GD25Q32JV，支持四线模式，可用于 XIP（就地执行） |
| 时钟分频 | 144 MHz / 2 = **72 MHz** | 满足 GD25Q32JV 要求（最大 104MHz） |
| 片选 (NCS) | 硬件控制 | CubeMX 中勾选 "Hardware NCS" |
| DMA | 不使能 | 标定参数读写次数少，无需 DMA |

> **存储规划**（QSPI Flash 地址映射）：
> | 地址范围 | 内容 | 大小 |
> |----------|------|------|
> | 0x0000 - 0x03FF | 标定参数头（魔数 4B + 版本 4B + 通道数 4B + 校验和 4B） | 16 B |
> | 0x0400 - 0x07FF | CH1 增益 (float) + 零偏 (int16) + 保留 | 8 B |
> | 0x0800 - 0x0BFF | CH2 增益 (float) + 零偏 (int16) + 保留 | 8 B |
> | 0x0C00 - 0x0FFF | CH3 增益 (float) + 零偏 (int16) + 保留 | 8 B |
> | 0x1000 - 0x13FF | CH4 增益 (float) + 零偏 (int16) + 保留 | 8 B |
> | 0x1400 - ... | 程序代码（XIP 执行） | 剩余空间 |
>
> 上电后读标定参数的伪代码逻辑：`read_qspi(0x0000, &header, 16)` → 验证魔数 `0xE4C101DA` → 验证 CRC32 → 若通过则加载增益/偏置，否则使用默认值（gain=1.0, offset=0）。

### 2.7 FMC 配置（外部 SRAM）

| 参数 | 值 | 说明 |
|---|-----|---|
| 芯片型号 | IS61WV204816BLL | 2M×16bit = 4MB，异步 SRAM |
| FMC 片选 | NE1 / NE2 | 根据 PCB 连线选择 |
| 数据宽度 | 16 位 |  |
| 地址线 | A0-A20 (21 位) |  |
| 操作模式 | **异步模式 A** (Asynchronous mode 1) | G4 FMC 仅支持 SRAM 异步模式 |
| 时序参数 | （见下方详细说明） | |

**STM32G473 FMC 时序参数说明**（与 F4/H7 不同，G4 系列简化版 FMC 只有 4 个时序参数）：

| CubeMX 参数名 | 建议值 | 说明 |
|---|---|---|
| **Address setup time** (ADDSET) | `2` | 地址建立时间（HCLK 周期数）。对应 IS61WV204816BLL 的 tSA（地址建立到片选/写使能时间），典型值 10ns |
| **Data setup time** (DATAST) | `3` | 数据建立时间（HCLK 周期数）。对应 IS61WV204816BLL 的 tRC（读周期时间）和 tWC（写周期时间），典型值 10ns |
| **Data hold time** (DATAHLD) | `1` | 数据保持时间（HCLK 周期数）。对应 IS61WV204816BLL 的 tOH（输出保持时间），典型值 3ns |
| **Bus turn around time** (BUSTURN) | `1` | 总线周转时间（HCLK 周期数）。读→写切换时的等待时间 |

> **时序裕量验算**（HCLK=144MHz → 1 周期 ≈ 6.94ns）：
> - 地址建立时间：2 × 6.94ns = **13.9ns** > IS61WV204816BLL 的 tSA（典型 10ns） ✅
> - 数据建立时间：3 × 6.94ns = **20.8ns** > IS61WV204816BLL 的 tRC（典型 10ns） ✅ 裕量充足
> - 如需更高性能，可尝试 ADDSET=1, DATAST=2（但建议先以上面保守值验证硬件正常后，再逐步降低）

**CubeMX 操作步骤**：
1. Pinout & Configuration → Connectivity → FMC → 在 "FMC 1" 中勾选对应的 **NE** 片选引脚
2. **Mode** → 选 "NOR/PSRAM/SRAM" 或 "SRAM"（取决于 CubeMX 版本）
3. **Parameter Settings**：
   - Bus Type: **SRAM**
   - Data Width: **16 bit**
   - Address Setup Time (ADDSET): **2** (HCLK cycles)
   - Data Setup Time (DATAST): **3** (HCLK cycles)
   - Data Hold Time (DATAHLD): **1** (HCLK cycles)
   - Bus Turnaround Time (BUSTURN): **1** (HCLK cycles)

> **⚠️ 注意**：STM32G473 的 FMC 不支持地址保持时间 ("Address hold time") 这个参数，这是和 F4/H7 系列的区别。G4 的 FMC 是简化版，只有 ADDSET、DATAST、DATAHLD、BUSTURN 四项。

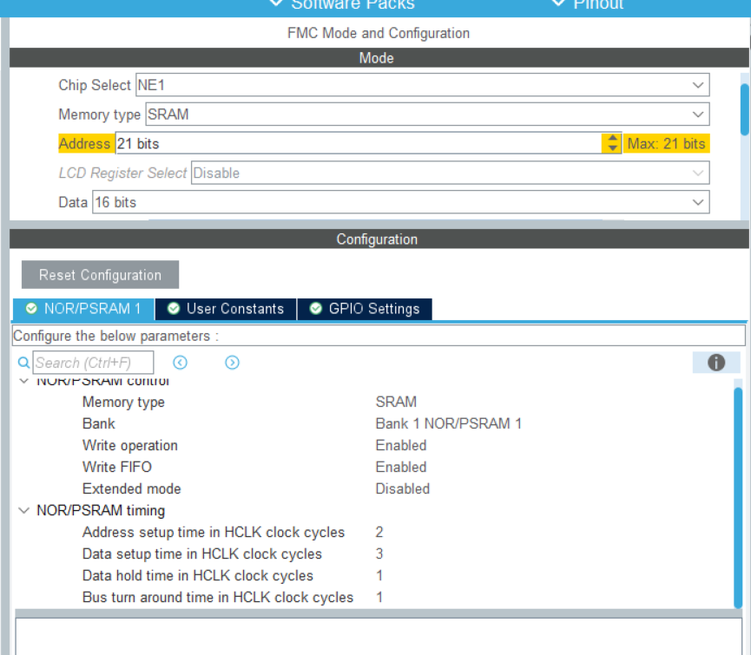
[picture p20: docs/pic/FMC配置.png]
FMC配置


### 2.8 UART 配置（多机同步触发）

| 参数 | 值 | 说明 |
|---|-----|---|
| 外设 | USART2 | UART 总线通过 74LVC1G07 开漏缓冲器线与 |
| 波特率 | 115200 bps | 或 1Mbps（同步触发帧极短，推荐更高波特率降低延迟） |
| 数据位 | 8 |  |
| 校验 | 无 |  |
| 停止位 | 1 |  |
| 模式 | **半双工** (单线) | 硬件线路为开漏线与总线，TX/RX 共用一线 |
| 中断 | 使能 RXNE 中断 | 收到数据即触发中断，vUART_Sync_Task 中解析帧内容 |

> **同步触发帧协议**（由 vUART_Sync_Task 处理）：
> | 字节 0 | 字节 1 | 说明 |
> |--------|--------|------|
> | 0xE4 | 0x01 | **同步触发帧**：收到后立即启动本地采集 |
> | 0xE4 | 0x02 | **同步停止帧**：停止采集 |
> | 0xE4 | 0xFF | **保活/心跳帧**：用于同步校准时间基准 |

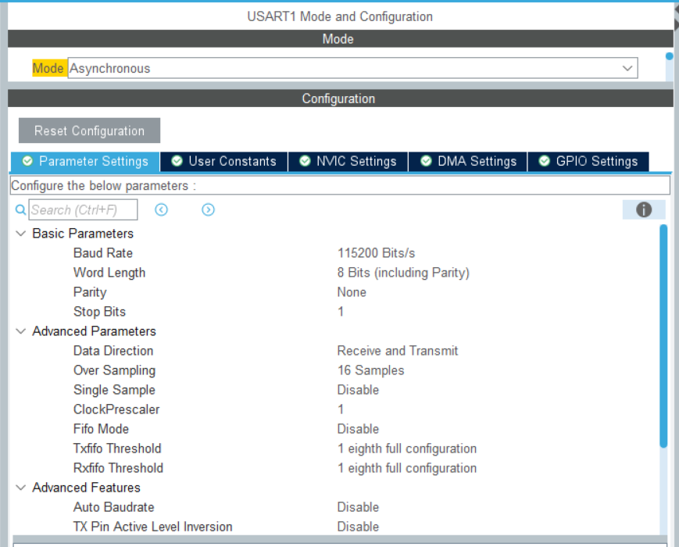
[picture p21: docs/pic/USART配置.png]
USART配置


### 2.9 FreeRTOS 配置

| 参数 | 值 | 说明 |
|---|-----|---|
| RTOS 版本 | CMSIS-RTOS V2 | CubeMX 默认 |
| 任务默认栈大小 | 256 words | 根据实际调整 |
| 总堆大小 | 16384 bytes | 考虑到队列、信号量、任务栈，建议增大至 16KB |
| 时基源 (TIM) | SysTick | 1ms 中断，但 FreeRTOS 建议使用专用的 TIM6 或 TIM7 作为时基（避免与 HAL 冲突） |
| 支持动态创建任务 | 是 |  |
| 使用队列、信号量 | 是 |  |

> **关于时基源**：CubeMX 生成的 FreeRTOS 默认使用 SysTick 作为时基。如果 HAL_Delay() 也使用 SysTick，建议在 FreeRTOSConfig.h 中将 `configUSE_TICKLESS_IDLE` 设为 0，或将 FreeRTOS 时基切换到 TIM6（在 CubeMX 的 "Pinout & Configuration → System Core → FreeRTOS → Config Parameters → configTICK_SOURCE" 中可选择）。

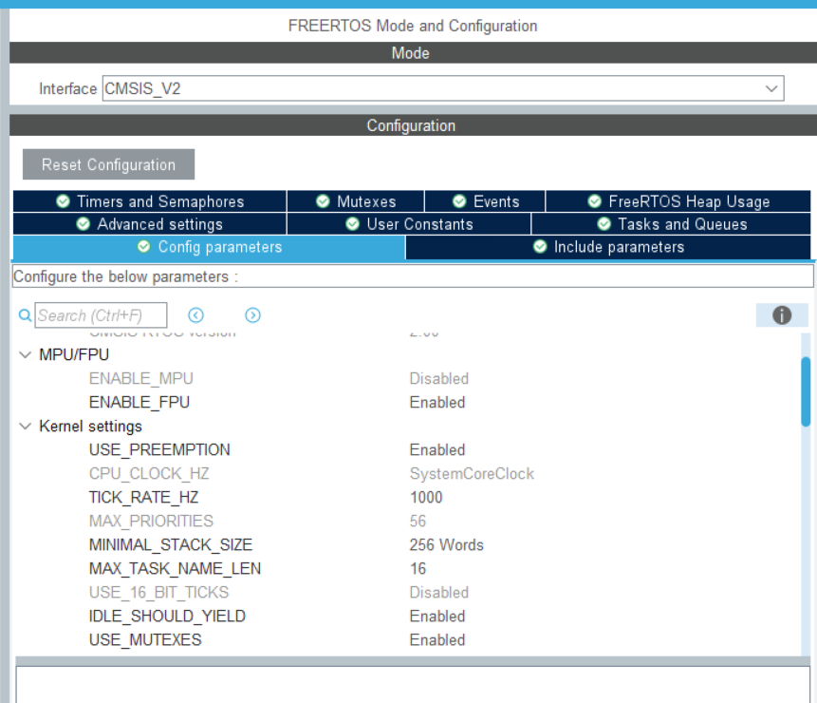
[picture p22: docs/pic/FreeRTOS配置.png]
FreeRTOS配置


### 2.10 GPIO 使用情况

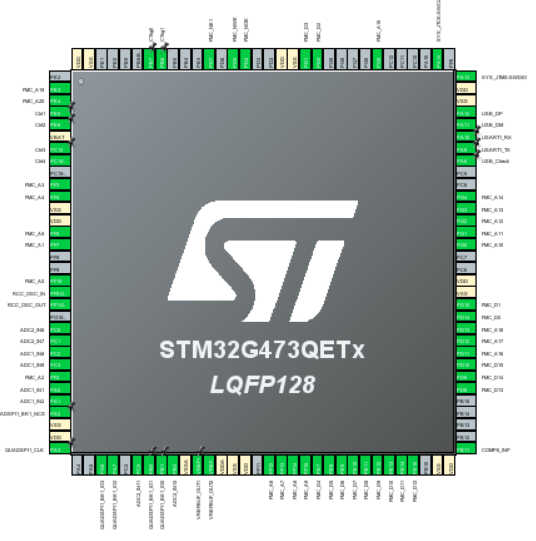
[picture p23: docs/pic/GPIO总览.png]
GPIO总览


## 3. 关键数据结构与算法

### 3.1 关键数据结构定义

**ADC 原始数据缓冲区**（每个 ADC 一个）：

```c
#define ADC_BUF_LEN      256     // 每通道环形缓冲区深度
#define ADC_CH_PER_ADC   2       // 每个 ADC 负责 2 个通道

// ADC1 缓冲区：存储 CH1, CH4 原始值
__attribute__((section(".sram_data"))) uint16_t adc1_buf[ADC_BUF_LEN][ADC_CH_PER_ADC];
// ADC2 缓冲区：存储 CH2, CH3 原始值
__attribute__((section(".sram_data"))) uint16_t adc2_buf[ADC_BUF_LEN][ADC_CH_PER_ADC];
```

**队列传递的数据结构**：

```c
typedef struct {
    uint16_t    ch[4];           // 4 通道 ADC 原始值 (12-bit, 右对齐)
    uint32_t    timestamp;       // 时间戳（来自 TIM1 计数器值，单位：1/144MHz ≈ 6.94ns，PSC=0 时）
    uint32_t    trigger_seq;     // 全局触发序号（上电后递增）
    uint8_t     mode_flags;      // Bit 0: 0=外部触发, 1=内部周期; Bit 1: 0=实时, 1=批量上传
    uint8_t     reserved[3];     // 对齐填充
} __attribute__((packed)) adc_data_t;
// 合计 4×2 + 4 + 4 + 1 + 3 = 16 字节
```

**标定参数结构**（存储在 QSPI Flash）：

```c
typedef struct {
    uint32_t    magic;           // 魔数 0xE4C101DA
    uint32_t    version;         // 标定数据版本
    uint32_t    num_channels;    // 通道数 (应=4)
    uint32_t    crc32;           // 校验和
    float       gain[4];         // 增益系数
    int16_t     offset[4];       // 零偏 (LSB)
    uint16_t    reserved[4];     // 保留
} __attribute__((packed)) calibration_t;
```

### 3.2 数据流与处理逻辑

**完整数据流**：

```
外部触发信号 → CMP整形 → TIM1从模式触发 → ADC1+ADC2同步转换
    → DMA循环搬运至 adc1_buf / adc2_buf
    → DMA传输完成中断 → xSemaphoreGiveFromISR → 唤醒 vADC_Task
    → vADC_Task 读取缓冲区，增益/偏置校正，封装 adc_data_t
    → xQueueSend → 消费端：
        → vUSB_Task: 格式化并 USB CDC 发送至 PC
        → vSRAM_Task: 写入外部 SRAM（批量上传模式使用）
```

**增益偏置校正公式**：

```
V_ch = ((adc_raw * V_REF) / 4096.0f - offset[ch]) * gain[ch]
```

其中：
- `adc_raw`：ADC 原始读数 (0~4095)
- `V_REF`：ADC 参考电压 = 2.5V（由电源设计中的 2.5V 激励电源提供）
- `offset[ch]`：该通道零偏（单位：伏特，通过短接输入端测量获得）
- `gain[ch]`：该通道增益系数（无量纲，通过输入标准电压标定获得）

> 由于硬件前端有 4 倍放大 + 1/4 衰减的组合，软件层面的 gain 校正主要补偿器件离散性误差，而非做满量程缩放。

### 3.3 SCPI 命令集定义（USB CDC 通信协议）

PC 通过 USB 虚拟串口发送 SCPI 风格命令控制采集模块，模块响应以 `\n` 结尾。

| 命令 | 功能 | 响应示例 |
|---|---|---|
| `*IDN?` | 查询设备信息 | `E4-Strain, V1.0, SN:xxxx\n` |
| `:ACQuire:STARt` | 启动采集 | `OK\n` |
| `:ACQuire:STOP` | 停止采集 | `OK\n` |
| `:TRIGger:SOURce EXT` | 设为外部触发模式 | `OK\n` |
| `:TRIGger:SOURce INT` | 设为内部周期性触发 | `OK\n` |
| `:TRIGger:INTerval <Hz>` | 设置内部触发频率 | `OK\n` |
| `:TRIGger:CHANnel <1-4>` | 选择触发源通道 | `OK\n` |
| `:CALibration:LOAD` | 从 QSPI 加载标定参数 | `OK\n` 或 `ERR:CRC\n` |
| `:CALibration:SAVE` | 保存当前标定参数到 QSPI | `OK\n` |
| `:FETCh?` | 查询单次最新采集数据 | `CH1:1.234,CH2:2.345,CH3:0.567,CH4:1.890\n` |
| `:UPLoad:STARt` | 启动批量上传（从 SRAM 读取） | `OK\n` 后持续发送数据包 |
| `:UPLoad:STOP` | 停止批量上传 | `OK\n` |
| `:SYSTem:ERRor?` | 查询错误状态 | `OK,0\n` 或 `ERR:code,msg\n` |

### 3.4 触发响应机制
处理过程：

1. **外部信号到来** → SMA 接口输入
2. **模拟开关 (ADG704)** → 选择触发源通道（由 GPIO SEL0, SEL1 控制）
3. **CMP 比较器** → 整形，输出至 TIM1
4. **TIM1 从模式** → 收到触发后产生 UEV，输出 TRGO
5. **ADC1+ADC2** → 同步开始转换
6. **DMA** → 循环搬运 ADC 结果至缓冲区
7. **DMA 传输完成中断** → `xSemaphoreGiveFromISR()` 释放信号量
8. **vADC_Task** → 获取信号量，处理数据

**周期性采集模式**：软件设置 `TIM1->SMCR` 的 SMS=0（关闭从模式），TIM1 按 ARR 频率自由运行，自动产生 UEV→TRGO 触发 ADC。

## 4. 系统启动流程

```mermaid
sequenceDiagram
    participant Power as 上电
    participant Sys as 系统初始化
    participant Cal as 标定参数加载
    participant RTOS as RTOS 启动
    participant Tasks as 用户任务

    Power->>Sys: 硬件复位
    Sys->>Sys: SystemClock_Config()          // 配置 HSE 24MHz → PLL → 144MHz 系统时钟
    Sys->>Sys: MX_GPIO_Init()                // GPIO, 调试串口, LED, 模拟开关控制
    Sys->>Sys: MX_DMA_Init()                 // DMA1 通道初始化
    Sys->>Sys: MX_ADC1_Init(), MX_ADC2_Init() // 双 ADC 同步模式
    Sys->>Sys: MX_COMP6_Init()               // 比较器（触发链）
    Sys->>Sys: MX_TIM1_Init()                // 触发链核心定时器
    Sys->>Sys: MX_USART2_UART_Init()         // 同步触发 UART
    Sys->>Sys: MX_USB_DEVICE_Init()          // USB CDC 虚拟串口
    Sys->>Sys: MX_FMC_Init()                 // 外部 SRAM 初始化
    Sys->>Sys: MX_QSPI_Init()                // 标定参数存储
    Sys->>Cal: 从 QSPI Flash 读取标定参数
    Cal-->>Sys: 校验魔数 + CRC，参数加载完成
    Sys->>RTOS: osKernelInitialize()
    RTOS->>Tasks: 创建 vADC_Task, vUSB_Task, vSRAM_Task, vUART_Sync_Task, vMonitor_Task
    Tasks-->>RTOS: 任务就绪
    RTOS->>RTOS: osKernelStart()
    Tasks->>Tasks: 进入任务循环
```

## 5. 测试与调试方法

### 5.1 单元测试计划

| 模块 | 测试内容 | 测试工具 | 通过标准 |
|---|---|---|---|
| 电源上电 | 各电压轨空载/负载电压纹波 | 万用表 + 示波器 | 3.3V±3%, ±4V±5%, 2.5V±1%, 纹波 < 50mVpp |
| MCU 最小系统 | SWD 连接、LED 闪烁 | ST-Link + CubeIDE | 正常识别芯片，LED 以 1Hz 闪烁 |
| FMC SRAM 读写 | 写 0x55AA/0xAA55 模式并回读 | 串口打印 | 数据正确，无 Bit 错误 |
| QSPI Flash 读写 | 写入 4KB 标定数据并回读 | 串口打印 | 数据完全一致，CRC 校验通过 |
| USB CDC 枚举 | PC 端识别为虚拟串口 | 设备管理器 | 成功出现 COM 端口 |
| CMP 比较器 | 输入三角波，观察输出翻转 | 信号发生器 + 示波器测 GPIO | 翻转阈值与设定值一致 |
| 触发链（全链路） | SMA 输入脉冲，测 ADC 转换完成 | 脉冲发生器 + 逻辑分析仪 | 触发到 ADC 数据就绪 < 2μs |
| ADC + DMA 循环 | 连续采集 10kHz 正弦波 | 信号发生器 + PC 端 Python 绘图 | 波形无明显失真，FFT 主峰正确 |
| USB 连续传输 | 持续发送 10000 包数据 (每包 4 通道) | PC 串口助手 | 无丢包，数据顺序正确 |
| 周期性采集模式 | 设置内部触发 1kHz，测实际频率 | 示波器测 DAC 或 GPIO 输出 | 频率误差 < 1% |
| 多机同步 (如有条件) | 2 块模块同步触发，对比采集起始时刻 | 同一信号源 + 双模块同时采集 | 两模块数据对齐，时差 < 1μs |
| SCPI 命令解析 | 逐条测试 §3.3 中定义的命令 | 串口助手手动输入 | 命令均有正确响应 |

### 5.2 调试接口

| 接口 | 用途 | 工具 | 说明 |
|---|---|---|---|
| SWD | 在线调试、断点、变量观察 | ST-Link + CubeIDE / Ozone | 可观察任务栈使用率、队列消息数 |
| USART1 (调试串口) | 调试日志输出 | 串口助手 (115200 8N1) | `printf` 重定向至此端口 |
| USB CDC (虚拟串口) | 数据上传 + SCPI 命令 | PC 端 Python 脚本 / 串口助手 | 数据通信主通道 |
| GPIO (测试点) | 示波器测量关键时序 | 示波器 | 可在 ISR 入口/出口翻转 GPIO 测量延迟 |

### 5.3 常见问题排查

| 现象 | 可能原因 | 排查方法 |
|---|---|---|
| USB 无法枚举 | USB DP/DM 差分阻抗不匹配、时钟不准 | 检查 PCB 走线 90Ω 阻抗，测量 48MHz USB 时钟 |
| ADC 数据全为 0 | ADC 未使能、触发源未连接、差分输入共模超出范围 | 用示波器测 ADC 输入引脚，检查 CubeMX ADC 配置 |
| DMA 数据错位 | 缓冲区大小不匹配、DMA 未正确配置循环模式 | 减少缓冲区大小调试，检查 DMA 地址递增设置 |
| 触发响应无反应 | CMP 阈值设置不当、TIM1 从模式配置错误 | 用示波器测 CMP 输出引脚，逐级排查触发链 |
| SRAM 数据读写错误 | FMC 时序参数不匹配、地址线错位 | 降低 FMC 时钟（增加等待周期），验证地址线连续性 |

## 6. 附录：软件-硬件接口对照表

下表列出了软件文档中涉及的硬件资源，以及对应的硬件文档章节，供设计时对照参考。

| 软件模块 | 硬件资源 | 硬件文档章节 | 关键引脚/参数 |
|---|---|---|---|
| ADC1 + ADC2 | STM32G473 内置 ADC | §2.2 MCU 最小系统 | 4 路差分输入（引脚号需确认） |
| 触发源选择 | ADG704 模拟开关 | §2.2.4 电平触发 | SEL0, SEL1 → GPIO |
| CMP 比较器 | STM32G473 内置 COMP6 | §2.2.4 电平触发 | 输入连接 ADG704 输出 |
| TIM1 | STM32G473 内置 TIM1 | §2.2 MCU | TRGO → ADC |
| USB CDC | USB Type-A + PRTR5V0U2X | §2.3 USB 接口 | DP/DM 90Ω 差分对 |
| FMC SRAM | IS61WV204816BLL | §2.5.2 SRAM | A0-A20, D0-D15, WE, OE, CE |
| QSPI Flash | GD25Q32JV | §2.5.1 QSPI Flash | 四线模式，72MHz |
| 多机同步 UART | 74LVC1G07 开漏缓冲 | §2.4部触发输入 | 半双工 UART bus |
| 电源系统 | TPS7A4701, SGM2059 等 | §2.6 电源与去耦 | 2.5V(ADC ref), 3.3V_A, 3.3V_D, ±4V |
| 调试 SWD | SWD 4-pin 接口 | §2.2 MCU 最小系统 | SWCLK, SWDIO, NRST |

## 8. 版本记录

| 版本 | 日期 | 修改内容 | 修改人 |
|---|---|---|---|
| V1.0 | 2026-06-04 | 初始版本 | EERNINUO |
| V1.1 | 2026-06-04 | 细化与修正：<br>• 修正时钟树计算（24MHz→PLL 系数）<br>• 补充 FMC/UART/CMP 配置章节<br>• 修正触发链描述（硬件链路不含 CPU 中断）<br>• 修正数据流（去除不存在的 SD 卡）<br>• 增加 SCPI 命令集定义<br>• 增加数据结构定义<br>• 增加软件-硬件接口对照表<br>• 增加需手动补充事项清单 | EERNINUO |

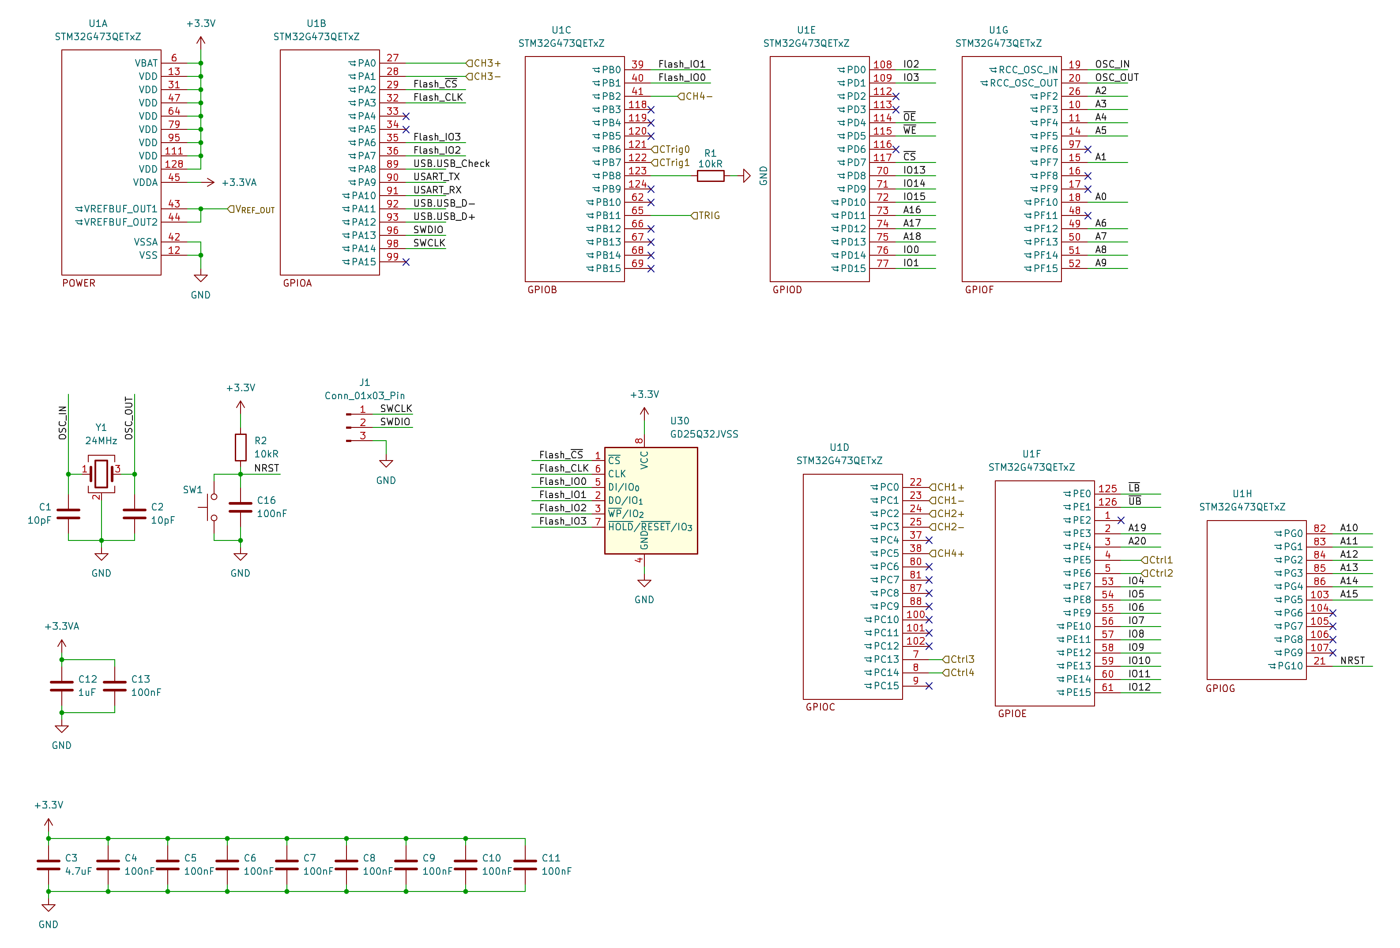
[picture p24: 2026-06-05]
docs/pic/MCU最小系统.png

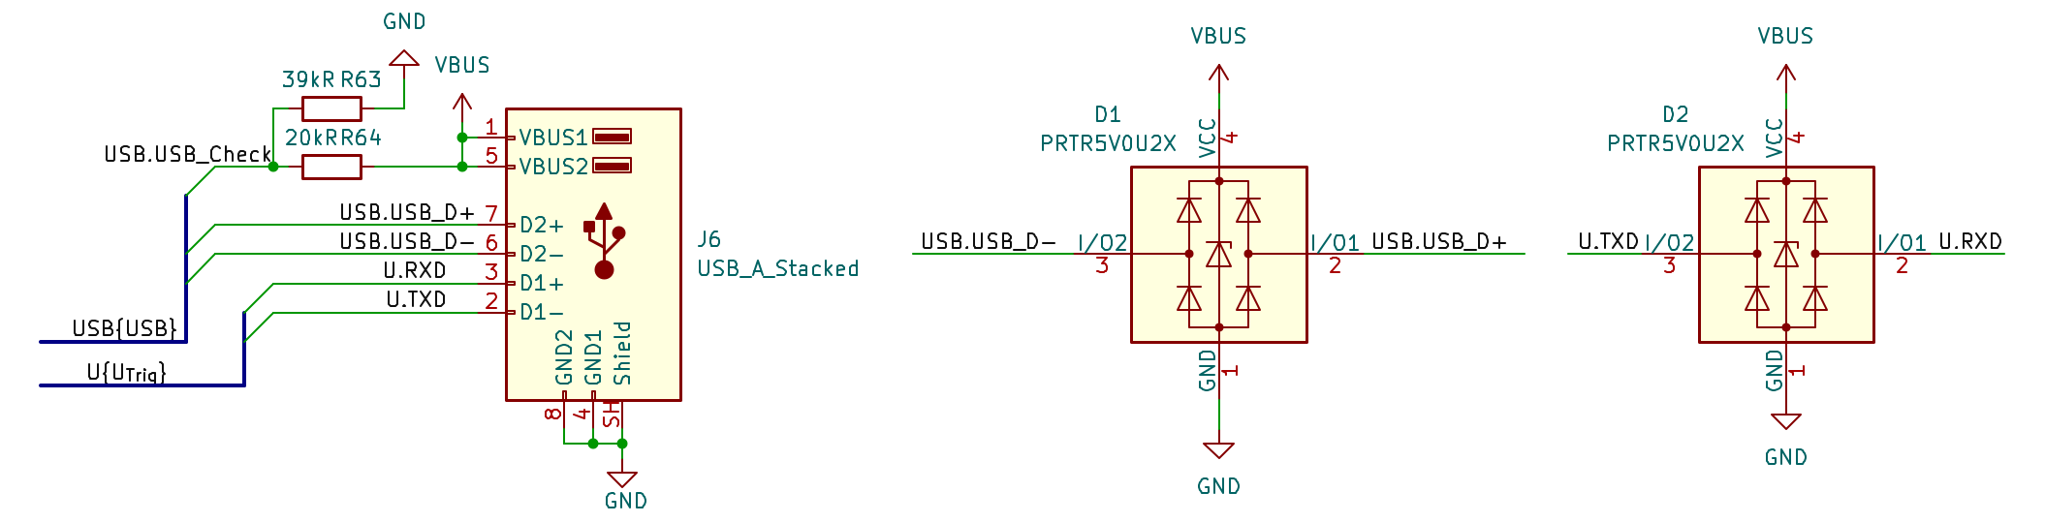
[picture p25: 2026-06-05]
docs/pic/USB接口原理图.png

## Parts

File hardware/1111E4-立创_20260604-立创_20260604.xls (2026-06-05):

立创商城BOM报价单
BOM配单编号：BOM260604008197 |  |  |  |  | 上传时间：2026-06-04 22:23:11 |  |  |  | 1.名称释义：MPQ--最小包装量；MOQ--最小起订量； 2.匹配结果为实时查询结果，库存和价格可能会有波动。如超过24小时，请在立创商城重新匹配后下单； 3.订货商品的价格仅供参考，请提交订单后确定。 4.如有部分物料未能成功匹配，需要整单购买，请联系商城客服。
BOM名称：1111E4-立创_20260604 |  |  |  |  | 采购套数：1
商品总价:￥614.33 (原价:￥647.25, 折扣:-￥32.92) 注：报价单总价不含待确认和无法匹配项 |  |  |  |  | 网址：https://bom.szlcsc.com/bom.html
原始需求 |  |  |  |  |  |  |  |  |  |  |  |  |  |  |  |  |  |  |  |  |  |  |  |  |  |  |  |  | 匹配结果 |  |  |  |  |  |  | 订单满足
型号 | 品牌 | 封装 | 名称 | 商品编号 | 原始型号 | 原始品牌 | C编码 | 编号 | 位号 | 数量 | 供应商编号 | 单价 | 匹配结果 | 商品名称 | 封装 | 参数 | 目录 | 商品链接 | 渠道 | 交期 | MOQ | MPQ | 库存 | 购买数量 | 单价(RMB) | 关税税率 | 小计(RMB) | 备注 | 匹配结果 | 商品名称 | 型号 | 品牌 | 封装 | 参数 | 目录 | 商品编号 | 商品链接 | 渠道 | 交期 | MOQ | MPQ | 库存 | 购买数量 | 单价(RMB) | 关税税率 | 小计(RMB) | 备注
CL05C100JB5NNNC | SAMSUNG(三星) | C_0402_1005Metric | 10pF | C32949 |  |  |  | 1 | C1, C2 | 2 |  |  | 系统匹配 | 10pF ±5% 50V | 0402 | 容值:10pF 精度:±5% 额定电压:50V 温度系数:C0G | 电容 | https://item.szlcsc.com/33914.html | 现货 | 4小时内发货 | 50 | 10000 | 30850 | 50 | 0.0317 | 0 | 1.59 |  | 系统匹配 | 10pF ±5% 50V | CL05C100JB5NNNC | SAMSUNG(三星) | 0402 | 容值：10pF 精度：±5% 额定电压：50V 温度系数：C0G | 电容 | C32949 | https://item.szlcsc.com/33914.html | 现货 | 4小时内发货 | 50 | 10000 | 30850 | 50 | 0.0317 | 0 | 1.59
CL10A475KO8NNNC | SAMSUNG(三星) | C_0603_1608Metric | 4.7uF | C19666 |  |  |  | 2 | C3, C17 | 2 |  |  | 系统匹配 | 4.7uF ±10% 16V | 0603 | 容值:4.7uF 精度:±10% 额定电压:16V 温度系数:X5R | 电容 | https://item.szlcsc.com/20375.html | 现货 | 4小时内发货 | 10 | 4000 | 55460 | 10 | 0.0856 | 0 | 0.86 |  | 系统匹配 | 4.7uF ±10% 16V | CL10A475KO8NNNC | SAMSUNG(三星) | 0603 | 容值：4.7uF 精度：±10% 额定电压：16V 温度系数：X5R | 电容 | C19666 | https://item.szlcsc.com/20375.html | 现货 | 4小时内发货 | 10 | 4000 | 55450 | 10 | 0.0856 | 0 | 0.86
CL05B104KO5NNNC | SAMSUNG(三星) | C_0402_1005Metric | 100nF | C1525 |  |  |  | 3 | C4, C13 | 2 |  |  | 系统匹配 | 100nF ±10% 16V | 0402 | 容值:100nF 精度:±10% 额定电压:16V 温度系数:X7R | 电容 | https://item.szlcsc.com/1877.html | 现货 | 4小时内发货 | 100 | 10000 | 10000 | 100 | 0.0104 | 0 | 1.04 |  | 系统匹配 | 100nF ±10% 16V | CL05B104KO5NNNC | SAMSUNG(三星) | 0402 | 容值：100nF 精度：±10% 额定电压：16V 温度系数：X7R | 电容 | C1525 | https://item.szlcsc.com/1877.html | 现货 | 4小时内发货 | 100 | 10000 | 10000 | 100 | 0.0104 | 0 | 1.04
CL10B104KA8NNNC | SAMSUNG(三星) | C_0603_1608Metric | 100nF | C1590 |  |  |  | 4 | C5, C6, C7, C8, C9, C10, C11, C15, C16, C18, C19, C45, C46, C48, C49, C50, C51, C52, C53, C54, C55, C56, C57, C71, C73, C75, C77, C78, C79, C80, C82, C86, C98, C100, C103, C104, C106, C109, C110, C111, C112, C113, C114, C115, C116, C117, C118, C120, C121, C122, C123, C145, C147, C156, C158, C159, C161, C165, C169, C170 | 60 |  |  | 系统匹配 | 100nF ±10% 25V | 0603 | 容值:100nF 精度:±10% 额定电压:25V 温度系数:X7R | 电容 | https://item.szlcsc.com/1942.html | 现货 | 4小时内发货 | 100 | 4000 | 4000 | 100 | 0.0297 | 0 | 2.97 |  | 系统匹配 | 100nF ±10% 25V | CL10B104KA8NNNC | SAMSUNG(三星) | 0603 | 容值：100nF 精度：±10% 额定电压：25V 温度系数：X7R | 电容 | C1590 | https://item.szlcsc.com/1942.html | 现货 | 4小时内发货 | 100 | 4000 | 4000 | 100 | 0.0297 | 0 | 2.97
CL05A105KA5NQNC | SAMSUNG(三星) | C_0402_1005Metric | 1uF | C52923 |  |  |  | 5 | C12 | 1 |  |  | 系统匹配 | 1uF ±10% 25V | 0402 | 容值:1uF 精度:±10% 额定电压:25V 温度系数:X5R | 电容 | https://item.szlcsc.com/53938.html | 现货 | 4小时内发货 | 100 | 10000 | 10000 | 100 | 0.0325 | 0 | 3.25 |  | 系统匹配 | 1uF ±10% 25V | CL05A105KA5NQNC | SAMSUNG(三星) | 0402 | 容值：1uF 精度：±10% 额定电压：25V 温度系数：X5R | 电容 | C52923 | https://item.szlcsc.com/53938.html | 现货 | 4小时内发货 | 100 | 10000 | 10100 | 100 | 0.0325 | 0 | 3.25
CL10A105KB8NNNC | SAMSUNG(三星) | C_0603_1608Metric | 1uF | C15849 |  |  |  | 6 | C14, C27, C28, C33, C34, C126, C127, C131, C132, C136, C137, C138, C139, C140, C141, C142, C143, C166, C167 | 19 |  |  | 系统匹配 | 1uF ±10% 50V | 0603 | 容值:1uF 精度:±10% 额定电压:50V 温度系数:X5R | 电容 | https://item.szlcsc.com/16531.html | 现货 | 4小时内发货 | 50 | 4000 | 4000 | 50 | 0.0665 | 0 | 3.33 |  | 系统匹配 | 1uF ±10% 50V | CL10A105KB8NNNC | SAMSUNG(三星) | 0603 | 容值：1uF 精度：±10% 额定电压：50V 温度系数：X5R | 电容 | C15849 | https://item.szlcsc.com/16531.html | 现货 | 4小时内发货 | 50 | 4000 | 4050 | 50 | 0.0665 | 0 | 3.33
CC0603JRNPO9BN121 | YAGEO(国巨) | C_0603_1608Metric | 120pF | C107035 |  |  |  | 7 | C20, C30, C40, C41 | 4 |  |  | 系统匹配 | 120pF ±5% 50V | 0603 | 容值:120pF 精度:±5% 额定电压:50V 温度系数:NP0 | 电容 | https://item.szlcsc.com/108251.html | 现货 | 4小时内发货 | 100 | 4000 | 419600 | 100 | 0.0387 | 0 | 3.87 |  | 系统匹配 | 120pF ±5% 50V | CC0603JRNPO9BN121 | YAGEO(国巨) | 0603 | 容值：120pF 精度：±5% 额定电压：50V 温度系数：NP0 | 电容 | C107035 | https://item.szlcsc.com/108251.html | 现货 | 4小时内发货 | 100 | 4000 | 419600 | 100 | 0.0387 | 0 | 3.87
CL10C101JB8NNNC | SAMSUNG(三星) | C_0603_1608Metric | 100pF | C14858 |  |  |  | 8 | C21, C22, C29, C31, C38, C39, C42, C43 | 8 |  |  | 系统匹配 | 100pF ±5% 50V | 0603 | 容值:100pF 精度:±5% 额定电压:50V 温度系数:C0G | 电容 | https://item.szlcsc.com/15530.html | 现货 | 4小时内发货 | 100 | 4000 | 40500 | 100 | 0.0317 | 0 | 3.17 |  | 系统匹配 | 100pF ±5% 50V | CL10C101JB8NNNC | SAMSUNG(三星) | 0603 | 容值：100pF 精度：±5% 额定电压：50V 温度系数：C0G | 电容 | C14858 | https://item.szlcsc.com/15530.html | 现货 | 4小时内发货 | 100 | 4000 | 40600 | 100 | 0.0317 | 0 | 3.17
CC0603JRNPO9BN751 | YAGEO(国巨) | C_0603_1608Metric | 750pF | C113798 |  |  |  | 9 | C23, C32, C124, C125 | 4 |  |  | 系统匹配 | 750pF ±5% 50V | 0603 | 容值:750pF 精度:±5% 额定电压:50V 温度系数:NP0 | 电容 | https://item.szlcsc.com/115034.html | 现货 | 4小时内发货 | 100 | 4000 | 15800 | 100 | 0.0363 | 0 | 3.63 |  | 系统匹配 | 750pF ±5% 50V | CC0603JRNPO9BN751 | YAGEO(国巨) | 0603 | 容值：750pF 精度：±5% 额定电压：50V 温度系数：NP0 | 电容 | C113798 | https://item.szlcsc.com/115034.html | 现货 | 4小时内发货 | 100 | 4000 | 15800 | 100 | 0.0363 | 0 | 3.63
CL05C101JB5NNNC | SAMSUNG(三星) | C_0402_1005Metric | 100pF | C26409 |  |  |  | 10 | C24, C25, C26, C35, C36, C37, C128, C129, C130, C133, C134, C135 | 12 |  |  | 系统匹配 | 100pF ±5% 50V | 0402 | 容值:100pF 精度:±5% 额定电压:50V 温度系数:C0G | 电容 | https://item.szlcsc.com/27153.html | 现货 | 4小时内发货 | 100 | 10000 | 95300 | 100 | 0.0292 | 0 | 2.92 |  | 系统匹配 | 100pF ±5% 50V | CL05C101JB5NNNC | SAMSUNG(三星) | 0402 | 容值：100pF 精度：±5% 额定电压：50V 温度系数：C0G | 电容 | C26409 | https://item.szlcsc.com/27153.html | 现货 | 4小时内发货 | 100 | 10000 | 95400 | 100 | 0.0292 | 0 | 2.92
CL10A106KP8NNNC | SAMSUNG(三星) | C_0603_1608Metric | 10uF | C19702 |  |  |  | 11 | C44, C47, C58, C59, C60, C61, C62, C63, C64, C65, C66, C67, C68, C69, C70, C72, C74, C76, C81, C83, C84, C85, C87, C88, C89, C90, C91, C92, C93, C94, C95, C96, C97, C99, C101, C102, C105, C107, C108, C119, C144, C146, C152, C153, C155, C157, C160, C162, C163 | 49 |  |  | 系统匹配 | 10uF ±10% 10V | 0603 | 容值:10uF 精度:±10% 额定电压:10V 温度系数:X5R | 电容 | https://item.szlcsc.com/20411.html | 现货 | 4小时内发货 | 20 | 4000 | 4000 | 60 | 0.085 | 0 | 5.10 |  | 系统匹配 | 10uF ±10% 10V | CL10A106KP8NNNC | SAMSUNG(三星) | 0603 | 容值：10uF 精度：±10% 额定电压：10V 温度系数：X5R | 电容 | C19702 | https://item.szlcsc.com/20411.html | 现货 | 4小时内发货 | 20 | 4000 | 4020 | 60 | 0.085 | 0 | 5.10
CL10A335KP8NNNC | SAMSUNG(三星) | C_0603_1608Metric | 3.3uF | C51412 |  |  |  | 12 | C148, C149, C150 | 3 |  |  | 系统匹配 | 3.3uF ±10% 10V | 0603 | 容值:3.3uF 精度:±10% 额定电压:10V 温度系数:X5R | 电容 | https://item.szlcsc.com/52425.html | 现货 | 4小时内发货 | 10 | 4000 | 4000 | 10 | 0.144 | 0 | 1.44 |  | 系统匹配 | 3.3uF ±10% 10V | CL10A335KP8NNNC | SAMSUNG(三星) | 0603 | 容值：3.3uF 精度：±10% 额定电压：10V 温度系数：X5R | 电容 | C51412 | https://item.szlcsc.com/52425.html | 现货 | 4小时内发货 | 10 | 4000 | 4000 | 10 | 0.144 | 0 | 1.44
CL31A476MPHNNNE | SAMSUNG(三星) | C_1206_3216Metric | 47uF | C96123 |  |  |  | 13 | C151, C154 | 2 |  |  | 系统匹配 | 47uF ±20% 10V | 1206 | 容值:47uF 精度:±20% 额定电压:10V 温度系数:X5R | 电容 | https://item.szlcsc.com/97327.html | 现货 | 4小时内发货 | 5 | 2000 | 6080 | 5 | 0.8743 | 0 | 4.37 |  | 系统匹配 | 47uF ±20% 10V | CL31A476MPHNNNE | SAMSUNG(三星) | 1206 | 容值：47uF 精度：±20% 额定电压：10V 温度系数：X5R | 电容 | C96123 | https://item.szlcsc.com/97327.html | 现货 | 4小时内发货 | 5 | 2000 | 5030 | 5 | 0.8743 | 0 | 4.37
PRTR5V0U2X | R+O(宏嘉诚) | SOT-143 | PRTR5V0U2X | C53446675 |  |  |  | 14 | D1, D2 | 2 |  |  | 系统匹配 | 单向小电容ESD保护二极管,低漏电流、低钳位电压 | SOT-143 | 反向截止电压(Vrwm):5V 钳位电压:15V 峰值脉冲电流(Ipp):5A 峰值脉冲功率(Ppp):75W 击穿电压(VBR):6V 反向电流(Ir):500nA 通道数:双路 工作温度:-55℃~+125℃ 类型:ESD Cj-结电容:0.65pF | 三极管/MOS管/晶体管 | https://item.szlcsc.com/56598097.html | 现货 | 4小时内发货 | 5 | 3000 | 3550 | 5 | 0.5096 | 0 | 2.55 |  | 系统匹配 | 单向小电容ESD保护二极管，低漏电流、低钳位电压 | PRTR5V0U2X | R+O(宏嘉诚) | SOT-143 | 反向截止电压(Vrwm)：5V 钳位电压：15V 峰值脉冲电流(Ipp)：5A 峰值脉冲功率(Ppp)：75W 击穿电压(VBR)：6V 反向电流(Ir)：500nA 通道数：双路 工作温度：-55℃~+125℃ 类型：ESD Cj-结电容：0.65pF | 三极管/MOS管/晶体管 | C53446675 | https://item.szlcsc.com/56598097.html | 现货 | 4小时内发货 | 5 | 3000 | 3550 | 5 | 0.5096 | 0 | 2.55
SMBJ5A |  | SMF | SMBJ5A | C113975 |  |  |  | 15 | D3 | 1 |  |  | 无法匹配 |  |  |  |  |  |  |  |  |  |  |  |  |  |  |  | 系统匹配 | 双向TVS 5V截止 峰值脉冲电流：65.3A@10/1000us | SMBJ5.0CA | MDD(辰达半导体) | DO-214AA(SMB) | 极性：双向 反向截止电压(Vrwm)：5V 钳位电压：9.2V 峰值脉冲电流(Ipp)：65.3A@10/1000us 峰值脉冲功率(Ppp)：600W@10/1000us 击穿电压(VBR)：7V 反向电流(Ir)：800uA 工作温度：-65℃~+150℃ 防护等级：- 类型：TVS Cj-结电容：- | 三极管/MOS管/晶体管 | C113975 | https://item.szlcsc.com/115214.html | 现货 | 4小时内发货 | 10 | 3000 | 374810 | 10 | 0.299 | 0 | 2.99
 |  |  | Vertical | C32713269 |  |  |  | 16 | J1 | 1 |  |  | 无法匹配 |  |  |  |  |  |  |  |  |  |  |  |  |  |  |  | 系统匹配 | 1x3P 间距:2.54mm 方针 直插 | HX PZ2.54-1x3P ZZ | hanxia(韩下) | 插件,P=2.54mm | 插针结构：1x3P 间距：2.54mm 行距：- 圆针/方针：方针 安装方式：直插 排数：单排 总PIN位数：3P 额定电流：3A 额定电压：1kV 配合针长度：6mm 塑高：2.5mm 端接针长度：3mm 触头材质：黄铜 触头镀层：金 工作温度：-40℃~+105℃ 颜色：黑色 附加特征：- | 连接器 | C32713269 | https://item.szlcsc.com/34444549.html | 现货 | 4小时内发货 | 5 | 2000 | 58195 | 5 | 0.1349 | 0 | 0.67
X0800HI-17-N0HF | XKB Connection(中国星坤) | RJ45_Amphenol_54602-x08_Horizontal | RJ45 | C2881013 |  |  |  | 17 | J2, J3, J4, J5 | 4 |  |  | 人工匹配 | X0800HI-17-N0HF | P=0.8mm | 连接器类型:- 间距:- 额定电流:- 额定电压:- 安装方式:- 行距:- 排数:- 每排PIN数:- 触头材质:- 触头镀层:- 工作温度:- | 连接器 | https://item.szlcsc.com/3091505.html | 订货 | 预估7-10个工作日 | 1 | 500 | 0 | 4 | 3.3 | 0 | 13.20 |  | 系统匹配 | X0800HI-17-N0HF | X0800HI-17-N0HF | XKB Connection(中国星坤) | P=0.8mm | 连接器类型：- 间距：- 额定电流：- 额定电压：- 安装方式：- 行距：- 排数：- 每排PIN数：- 触头材质：- 触头镀层：- 工作温度：- | 连接器 | C2881013 | https://item.szlcsc.com/3091505.html | 订货 | 预估7-10个工作日 | 1 | 500 | 0 | 4 | 3.3 | 0 | 13.20
 |  |  |  | C456021 |  |  |  | 18 | J6 | 1 |  |  | 无法匹配 |  |  |  |  |  |  |  |  |  |  |  |  |  |  |  | 系统匹配 | Type-A弯插双层母座 | AF SS-JB17.6 | SHOU HAN(首韩) | 弯插 | 连接器类型：Type-A 协议标准：USB 2.0 公母：母 安装方式：弯插 触点数量：4Px2 端口数量：2 额定电流 - 电源：1.5A 额定电压：30V 插拔寿命：5千次 附加特征：- 中心高度(CH)：- 体长(L)：17.6mm 胶芯颜色：白色 工作温度：-25℃~+85℃ | 连接器 | C456021 | https://item.szlcsc.com/458828.html | 现货 | 4小时内发货 | 5 | 100 | 45880 | 5 | 0.801895 | 0 | 4.01
 |  |  |  | C386763 |  |  |  | 19 | J7 | 1 |  |  | 无法匹配 |  |  |  |  |  |  |  |  |  |  |  |  |  |  |  | 系统匹配 | 直插 不带LED | R-RJ45S08P-B000 | Ckmtw(灿科盟) | 插件 | 连接器类型：RJ45插座 安装方式：直插 端口数量：1 LED：不带LED 屏蔽：有屏蔽 等级：- 附加特征：鱼叉脚(塑料) 触头材质：磷青铜 触头镀层：金 工作温度：0℃~+70℃ | 连接器 | C386763 | https://item.szlcsc.com/360870.html | 现货 | 4小时内发货 | 1 | 80 | 30062 | 1 | 3.2 | 0 | 3.20
RT0603BRD0710KL | YAGEO(国巨) | R_0603_1608Metric | 10kR | C95204 |  |  |  | 20 | R1, R2, R65, R66, R68 | 5 |  |  | 系统匹配 | 薄膜电阻 10kΩ ±0.1% 100mW | 0603 | 电阻类型:薄膜电阻 阻值:10kΩ 精度:±0.1% 功率:100mW 工作电压:75V 温度系数:±25ppm/℃ 工作温度:-55℃~+155℃ | 电阻 | https://item.szlcsc.com/96405.html | 现货 | 4小时内发货 | 20 | 5000 | 79360 | 20 | 0.1423 | 0 | 2.85 |  | 系统匹配 | 薄膜电阻 10kΩ ±0.1% 100mW | RT0603BRD0710KL | YAGEO(国巨) | 0603 | 电阻类型：薄膜电阻 阻值：10kΩ 精度：±0.1% 功率：100mW 工作电压：75V 温度系数：±25ppm/℃ 工作温度：-55℃~+155℃ | 电阻 | C95204 | https://item.szlcsc.com/96405.html | 现货 | 4小时内发货 | 20 | 5000 | 78940 | 20 | 0.1423 | 0 | 2.85
RT0603BRD071KL | YAGEO(国巨) | R_0603_1608Metric | 1kR | C110776 |  |  |  | 21 | R3, R4, R12, R14, R18, R19, R26, R28, R34, R35, R36, R37, R52, R54, R61, R62 | 16 |  |  | 系统匹配 | 薄膜电阻 1kΩ ±0.1% 100mW | 0603 | 电阻类型:薄膜电阻 阻值:1kΩ 精度:±0.1% 功率:100mW 工作电压:75V 温度系数:±25ppm/℃ 工作温度:-55℃~+155℃ | 电阻 | https://item.szlcsc.com/112001.html | 现货 | 4小时内发货 | 20 | 5000 | 183440 | 20 | 0.1396 | 0 | 2.79 |  | 系统匹配 | 薄膜电阻 1kΩ ±0.1% 100mW | RT0603BRD071KL | YAGEO(国巨) | 0603 | 电阻类型：薄膜电阻 阻值：1kΩ 精度：±0.1% 功率：100mW 工作电压：75V 温度系数：±25ppm/℃ 工作温度：-55℃~+155℃ | 电阻 | C110776 | https://item.szlcsc.com/112001.html | 现货 | 4小时内发货 | 20 | 5000 | 183440 | 20 | 0.1396 | 0 | 2.79
0603WAJ0121T5E | UNI-ROYAL(厚声) | R_0603_1608Metric | 120R | C25205 |  |  |  | 22 | R5, R20, R39, R40 | 4 |  |  | 系统匹配 | 120Ω ±5% 100mW 厚膜电阻 | 0603 | 电阻类型:厚膜电阻 阻值:120Ω 精度:±5% 功率:100mW 工作电压:75V 温度系数:±100ppm/℃ 工作温度:-55℃~+155℃ | 电阻 | https://item.szlcsc.com/25948.html | 现货 | 4小时内发货 | 100 | 5000 | 221900 | 100 | 0.007 | 0 | 0.70 |  | 系统匹配 | 120Ω ±5% 100mW 厚膜电阻 | 0603WAJ0121T5E | UNI-ROYAL(厚声) | 0603 | 电阻类型：厚膜电阻 阻值：120Ω 精度：±5% 功率：100mW 工作电压：75V 温度系数：±100ppm/℃ 工作温度：-55℃~+155℃ | 电阻 | C25205 | https://item.szlcsc.com/25948.html | 现货 | 4小时内发货 | 100 | 5000 | 221800 | 100 | 0.007 | 0 | 0.70
0603WAF8451T5E | UNI-ROYAL(厚声) | R_0603_1608Metric | 8.45kR | C14892 |  |  |  | 23 | R6, R22, R45, R46 | 4 |  |  | 系统匹配 | 8.45kΩ ±1% 100mW 厚膜电阻 | 0603 | 电阻类型:厚膜电阻 阻值:8.45kΩ 精度:±1% 功率:100mW 工作电压:75V 温度系数:±100ppm/℃ 工作温度:-55℃~+155℃ | 电阻 | https://item.szlcsc.com/15564.html | 现货 | 4小时内发货 | 100 | 5000 | 63200 | 100 | 0.0085 | 0 | 0.85 |  | 系统匹配 | 8.45kΩ ±1% 100mW 厚膜电阻 | 0603WAF8451T5E | UNI-ROYAL(厚声) | 0603 | 电阻类型：厚膜电阻 阻值：8.45kΩ 精度：±1% 功率：100mW 工作电压：75V 温度系数：±100ppm/℃ 工作温度：-55℃~+155℃ | 电阻 | C14892 | https://item.szlcsc.com/15564.html | 现货 | 4小时内发货 | 100 | 5000 | 63200 | 100 | 0.0085 | 0 | 0.85
0603WAF6191T5E | UNI-ROYAL(厚声) | R_0603_1608Metric | 6.19kR | C25978 |  |  |  | 24 | R7, R21, R42, R44 | 4 |  |  | 系统匹配 | 6.19kΩ ±1% 100mW 厚膜电阻 | 0603 | 电阻类型:厚膜电阻 阻值:6.19kΩ 精度:±1% 功率:100mW 工作电压:75V 温度系数:±100ppm/℃ 工作温度:-55℃~+155℃ | 电阻 | https://item.szlcsc.com/26721.html | 现货 | 4小时内发货 | 100 | 5000 | 45700 | 100 | 0.0079 | 0 | 0.79 |  | 系统匹配 | 6.19kΩ ±1% 100mW 厚膜电阻 | 0603WAF6191T5E | UNI-ROYAL(厚声) | 0603 | 电阻类型：厚膜电阻 阻值：6.19kΩ 精度：±1% 功率：100mW 工作电压：75V 温度系数：±100ppm/℃ 工作温度：-55℃~+155℃ | 电阻 | C25978 | https://item.szlcsc.com/26721.html | 现货 | 4小时内发货 | 100 | 5000 | 45700 | 100 | 0.0079 | 0 | 0.79
0603WAF2151T5E | UNI-ROYAL(厚声) | R_0603_1608Metric | 2.15kR | C22901 |  |  |  | 25 | R8, R23, R47, R48 | 4 |  |  | 系统匹配 | 2.15kΩ ±1% 100mW 厚膜电阻 | 0603 | 电阻类型:厚膜电阻 阻值:2.15kΩ 精度:±1% 功率:100mW 工作电压:75V 温度系数:±100ppm/℃ 工作温度:-55℃~+155℃ | 电阻 | https://item.szlcsc.com/23628.html | 现货 | 4小时内发货 | 100 | 5000 | 300 | 100 | 0.0075 | 0 | 0.75 |  | 系统匹配 | 2.15kΩ ±1% 100mW 厚膜电阻 | 0603WAF2151T5E | UNI-ROYAL(厚声) | 0603 | 电阻类型：厚膜电阻 阻值：2.15kΩ 精度：±1% 功率：100mW 工作电压：75V 温度系数：±100ppm/℃ 工作温度：-55℃~+155℃ | 电阻 | C22901 | https://item.szlcsc.com/23628.html | 现货 | 4小时内发货 | 100 | 5000 | 300 | 100 | 0.0075 | 0 | 0.75
RT0603BRD073K92L | YAGEO(国巨) | R_0603_1608Metric | 3.92kR | C728591 |  |  |  | 26 | R9, R24, R49, R50 | 4 |  |  | 系统匹配 | 薄膜电阻 3.92kΩ ±0.1% 100mW | 0603 | 电阻类型:薄膜电阻 阻值:3.92kΩ 精度:±0.1% 功率:100mW 工作电压:75V 温度系数:±25ppm/℃ 工作温度:-55℃~+155℃ | 电阻 | https://item.szlcsc.com/775906.html | 现货 | 4小时内发货 | 20 | 5000 | 2740 | 20 | 0.1671 | 0 | 3.34 |  | 系统匹配 | 薄膜电阻 3.92kΩ ±0.1% 100mW | RT0603BRD073K92L | YAGEO(国巨) | 0603 | 电阻类型：薄膜电阻 阻值：3.92kΩ 精度：±0.1% 功率：100mW 工作电压：75V 温度系数：±25ppm/℃ 工作温度：-55℃~+155℃ | 电阻 | C728591 | https://item.szlcsc.com/775906.html | 现货 | 4小时内发货 | 20 | 5000 | 2740 | 20 | 0.1671 | 0 | 3.34
RT0603BRE078KL | YAGEO(国巨) | R_0603_1608Metric | 8kR | C862311 |  |  |  | 27 | R10, R27, R57, R58 | 4 |  |  | 系统匹配 | 薄膜电阻 8kΩ ±0.1% 100mW | 0603 | 电阻类型:薄膜电阻 阻值:8kΩ 精度:±0.1% 功率:100mW 工作电压:75V 温度系数:±50ppm/℃ 工作温度:-55℃~+155℃ | 电阻 | https://item.szlcsc.com/922391.html | 现货 | 4小时内发货 | 20 | 5000 | 3440 | 20 | 0.1851 | 0 | 3.70 |  | 系统匹配 | 薄膜电阻 8kΩ ±0.1% 100mW | RT0603BRE078KL | YAGEO(国巨) | 0603 | 电阻类型：薄膜电阻 阻值：8kΩ 精度：±0.1% 功率：100mW 工作电压：75V 温度系数：±50ppm/℃ 工作温度：-55℃~+155℃ | 电阻 | C862311 | https://item.szlcsc.com/922391.html | 现货 | 4小时内发货 | 20 | 5000 | 3440 | 20 | 0.1851 | 0 | 3.70
CR167001F | Meritek | R_0603_1608Metric | 7kR | C4151218 |  |  |  | 28 | R11, R25, R51, R53 | 4 |  |  | 系统匹配 | 厚膜电阻 7kΩ ±1% 100mW | 0603 | 电阻类型:厚膜电阻 阻值:7kΩ 精度:±1% 功率:100mW 温度系数:±100ppm/℃ 工作温度:-55℃~+155℃ | 电阻 | https://item.szlcsc.com/4720521.html | 订货 | 预估7-10个工作日 | 1 | 5000 | 0 | 4 | 0.0105 | 0 | 0.04 |  | 系统匹配 | 厚膜电阻 7kΩ ±1% 100mW | CR167001F | Meritek | 0603 | 电阻类型：厚膜电阻 阻值：7kΩ 精度：±1% 功率：100mW 温度系数：±100ppm/℃ 工作温度：-55℃~+155℃ | 电阻 | C4151218 | https://item.szlcsc.com/4720521.html | 订货 | 预估7-10个工作日 | 1 | 5000 | 0 | 4 | 0.0105 | 0 | 0.04
0603WAF2672T5E | UNI-ROYAL(厚声) | R_0603_1608Metric | 26.7kR | C22923 |  |  |  | 29 | R13, R31, R33, R41 | 4 |  |  | 系统匹配 | 26.7kΩ ±1% 100mW 厚膜电阻 | 0603 | 电阻类型:厚膜电阻 阻值:26.7kΩ 精度:±1% 功率:100mW 工作电压:75V 温度系数:±100ppm/℃ 工作温度:-55℃~+155℃ | 电阻 | https://item.szlcsc.com/23650.html | 现货 | 4小时内发货 | 100 | 5000 | 20400 | 100 | 0.0082 | 0 | 0.82 |  | 系统匹配 | 26.7kΩ ±1% 100mW 厚膜电阻 | 0603WAF2672T5E | UNI-ROYAL(厚声) | 0603 | 电阻类型：厚膜电阻 阻值：26.7kΩ 精度：±1% 功率：100mW 工作电压：75V 温度系数：±100ppm/℃ 工作温度：-55℃~+155℃ | 电阻 | C22923 | https://item.szlcsc.com/23650.html | 现货 | 4小时内发货 | 100 | 5000 | 20400 | 100 | 0.0082 | 0 | 0.82
0402WGF499JTCE | UNI-ROYAL(厚声) | R_0402_1005Metric | 49.9R | C25120 |  |  |  | 30 | R15, R16, R29, R30, R55, R56, R59, R60 | 8 |  |  | 系统匹配 | 49.9Ω ±1% 62.5mW 厚膜电阻 | 0402 | 电阻类型:厚膜电阻 阻值:49.9Ω 精度:±1% 功率:62.5mW 工作电压:50V 温度系数:±100ppm/℃ 工作温度:-55℃~+155℃ | 电阻 | https://item.szlcsc.com/25863.html | 现货 | 4小时内发货 | 100 | 10000 | 3660000 | 100 | 0.005643 | 0 | 0.56 |  | 系统匹配 | 49.9Ω ±1% 62.5mW 厚膜电阻 | 0402WGF499JTCE | UNI-ROYAL(厚声) | 0402 | 电阻类型：厚膜电阻 阻值：49.9Ω 精度：±1% 功率：62.5mW 工作电压：50V 温度系数：±100ppm/℃ 工作温度：-55℃~+155℃ | 电阻 | C25120 | https://item.szlcsc.com/25863.html | 现货 | 4小时内发货 | 100 | 10000 | 3659900 | 100 | 0.005643 | 0 | 0.56
0603WAF1242T5E | UNI-ROYAL(厚声) | R_0603_1608Metric | 12.4kR | C22865 |  |  |  | 31 | R17, R32, R38, R43 | 4 |  |  | 系统匹配 | 12.4kΩ ±1% 100mW 厚膜电阻 | 0603 | 电阻类型:厚膜电阻 阻值:12.4kΩ 精度:±1% 功率:100mW 工作电压:75V 温度系数:±100ppm/℃ 工作温度:-55℃~+155℃ | 电阻 | https://item.szlcsc.com/23592.html | 现货 | 4小时内发货 | 100 | 5000 | 11600 | 100 | 0.008811 | 0 | 0.88 |  | 系统匹配 | 12.4kΩ ±1% 100mW 厚膜电阻 | 0603WAF1242T5E | UNI-ROYAL(厚声) | 0603 | 电阻类型：厚膜电阻 阻值：12.4kΩ 精度：±1% 功率：100mW 工作电压：75V 温度系数：±100ppm/℃ 工作温度：-55℃~+155℃ | 电阻 | C22865 | https://item.szlcsc.com/23592.html | 现货 | 4小时内发货 | 100 | 5000 | 11600 | 100 | 0.008811 | 0 | 0.88
0603WAF3902T5E | UNI-ROYAL(厚声) | R_0603_1608Metric | 39kR | C23153 |  |  |  | 32 | R63 | 1 |  |  | 系统匹配 | 39kΩ ±1% 100mW 厚膜电阻 | 0603 | 电阻类型:厚膜电阻 阻值:39kΩ 精度:±1% 功率:100mW 工作电压:75V 温度系数:±100ppm/℃ 工作温度:-55℃~+155℃ | 电阻 | https://item.szlcsc.com/23880.html | 现货 | 4小时内发货 | 100 | 5000 | 503200 | 100 | 0.0093 | 0 | 0.93 |  | 系统匹配 | 39kΩ ±1% 100mW 厚膜电阻 | 0603WAF3902T5E | UNI-ROYAL(厚声) | 0603 | 电阻类型：厚膜电阻 阻值：39kΩ 精度：±1% 功率：100mW 工作电压：75V 温度系数：±100ppm/℃ 工作温度：-55℃~+155℃ | 电阻 | C23153 | https://item.szlcsc.com/23880.html | 现货 | 4小时内发货 | 100 | 5000 | 503200 | 100 | 0.0093 | 0 | 0.93
0603WAJ0203T5E | UNI-ROYAL(厚声) | R_0603_1608Metric | 20kR | C25586 |  |  |  | 33 | R64 | 1 |  |  | 系统匹配 | 20kΩ ±5% 100mW 厚膜电阻 | 0603 | 电阻类型:厚膜电阻 阻值:20kΩ 精度:±5% 功率:100mW 工作电压:75V 温度系数:±100ppm/℃ 工作温度:-55℃~+155℃ | 电阻 | https://item.szlcsc.com/26329.html | 现货 | 4小时内发货 | 100 | 5000 | 215400 | 100 | 0.0076 | 0 | 0.76 |  | 系统匹配 | 20kΩ ±5% 100mW 厚膜电阻 | 0603WAJ0203T5E | UNI-ROYAL(厚声) | 0603 | 电阻类型：厚膜电阻 阻值：20kΩ 精度：±5% 功率：100mW 工作电压：75V 温度系数：±100ppm/℃ 工作温度：-55℃~+155℃ | 电阻 | C25586 | https://item.szlcsc.com/26329.html | 现货 | 4小时内发货 | 100 | 5000 | 215400 | 100 | 0.0076 | 0 | 0.76
0603WAF2402T5E | UNI-ROYAL(厚声) | R_0603_1608Metric | 24kR | C23352 |  |  |  | 34 | R67 | 1 |  |  | 系统匹配 | 24kΩ ±1% 100mW 厚膜电阻 | 0603 | 电阻类型:厚膜电阻 阻值:24kΩ 精度:±1% 功率:100mW 工作电压:75V 温度系数:±100ppm/℃ 工作温度:-55℃~+155℃ | 电阻 | https://item.szlcsc.com/24085.html | 现货 | 4小时内发货 | 100 | 5000 | 101000 | 100 | 0.009009 | 0 | 0.90 |  | 系统匹配 | 24kΩ ±1% 100mW 厚膜电阻 | 0603WAF2402T5E | UNI-ROYAL(厚声) | 0603 | 电阻类型：厚膜电阻 阻值：24kΩ 精度：±1% 功率：100mW 工作电压：75V 温度系数：±100ppm/℃ 工作温度：-55℃~+155℃ | 电阻 | C23352 | https://item.szlcsc.com/24085.html | 现货 | 4小时内发货 | 100 | 5000 | 101000 | 100 | 0.009009 | 0 | 0.90
0603WAJ0473T5E | UNI-ROYAL(厚声) | R_0603_1608Metric | 47kR | C25600 |  |  |  | 35 | R69 | 1 |  |  | 系统匹配 | 47kΩ ±5% 100mW 厚膜电阻 | 0603 | 电阻类型:厚膜电阻 阻值:47kΩ 精度:±5% 功率:100mW 工作电压:75V 温度系数:±100ppm/℃ 工作温度:-55℃~+155℃ | 电阻 | https://item.szlcsc.com/26343.html | 现货 | 4小时内发货 | 100 | 5000 | 16400 | 100 | 0.0072 | 0 | 0.72 |  | 系统匹配 | 47kΩ ±5% 100mW 厚膜电阻 | 0603WAJ0473T5E | UNI-ROYAL(厚声) | 0603 | 电阻类型：厚膜电阻 阻值：47kΩ 精度：±5% 功率：100mW 工作电压：75V 温度系数：±100ppm/℃ 工作温度：-55℃~+155℃ | 电阻 | C25600 | https://item.szlcsc.com/26343.html | 现货 | 4小时内发货 | 100 | 5000 | 16400 | 100 | 0.0072 | 0 | 0.72
0603WAJ0153T5E | UNI-ROYAL(厚声) | R_0603_1608Metric | 15kR | C25581 |  |  |  | 36 | R70 | 1 |  |  | 系统匹配 | 15kΩ ±5% 100mW 厚膜电阻 | 0603 | 电阻类型:厚膜电阻 阻值:15kΩ 精度:±5% 功率:100mW 工作电压:75V 温度系数:±100ppm/℃ 工作温度:-55℃~+155℃ | 电阻 | https://item.szlcsc.com/26324.html | 现货 | 4小时内发货 | 100 | 5000 | 65500 | 100 | 0.006831 | 0 | 0.68 |  | 系统匹配 | 15kΩ ±5% 100mW 厚膜电阻 | 0603WAJ0153T5E | UNI-ROYAL(厚声) | 0603 | 电阻类型：厚膜电阻 阻值：15kΩ 精度：±5% 功率：100mW 工作电压：75V 温度系数：±100ppm/℃ 工作温度：-55℃~+155℃ | 电阻 | C25581 | https://item.szlcsc.com/26324.html | 现货 | 4小时内发货 | 100 | 5000 | 65500 | 100 | 0.006831 | 0 | 0.68
FSMSM | TE Connectivity(泰科电子) | SW_SPST_FSMSM | SW_MEC_5G | C7278475 |  |  |  | 37 | SW1 | 1 |  |  | 系统匹配 | 24V 50mA | SMD,6x3.5mm | 电路结构:单刀单掷-常开 按钮形状:圆形按钮 作用力:1.8N 安装方式:立贴 开关长度:2.99mm 开关宽度:1.07mm 开关高度:4.57mm 触点电流:50mA 额定电压:24V 引脚样式:鸥翼型 工作寿命:2万次 工作温度:-35℃~+85℃ | 按键/开关 | https://item.szlcsc.com/8247649.html | 现货 | 4小时内发货 | 5 | 1000 | 1250 | 5 | 2.4051 | 0 | 12.03 |  | 系统匹配 | 24V 50mA | FSMSM | TE Connectivity(泰科电子) | SMD,6x3.5mm | 电路结构：单刀单掷-常开 按钮形状：圆形按钮 作用力：1.8N 安装方式：立贴 开关长度：2.99mm 开关宽度：1.07mm 开关高度：4.57mm 触点电流：50mA 额定电压：24V 引脚样式：鸥翼型 工作寿命：2万次 工作温度：-35℃~+85℃ | 按键/开关 | C7278475 | https://item.szlcsc.com/8247649.html | 现货 | 4小时内发货 | 5 | 1000 | 1250 | 5 | 2.4051 | 0 | 12.03
PS-22F02-S-B | HOOYA(皓宇电子) | SW-TH_G-SWITCH-PS-22F03N | PS-22F02 | C2939306 |  |  |  | 38 | SW2 | 1 |  |  | 系统匹配 | PS-22F02-S-B | 插件 | 电路结构:双刀双掷 开关高度:24.6mm 开关长度:10mm 开关宽度:7.75mm 按键形状:方形柱塞 按键/盖帽颜色:黑色 | 按键/开关 | https://item.szlcsc.com/3300253.html | 现货 | 4小时内发货 | 5 | 500 | 555 | 5 | 0.80807 | 0 | 4.04 |  | 系统匹配 | PS-22F02-S-B | PS-22F02-S-B | HOOYA(皓宇电子) | 插件 | 电路结构：双刀双掷 开关高度：24.6mm 开关长度：10mm 开关宽度：7.75mm 按键形状：方形柱塞 按键/盖帽颜色：黑色 | 按键/开关 | C2939306 | https://item.szlcsc.com/3300253.html | 现货 | 4小时内发货 | 5 | 500 | 555 | 5 | 0.80807 | 0 | 4.04
STM32G473QE |  | LQFP-128 |  | C730119 |  |  |  | 39 | U1 | 1 |  |  | 无法匹配 |  |  |  |  |  |  |  |  |  |  |  |  |  |  |  | 系统匹配 | 带DSP和FPU的170MHz主流ARM Cortex-M4 MCU，具有512 KB Flash存储器、数学加速器和高模拟电平集成 | STM32G473QET6 | ST(意法半导体) | LQFP-128(14x14) | CPU内核：ARM Cortex-M4 CPU最大主频：170MHz CPU位数：32 Bit 程序存储容量：512KB 程序存储器类型：FLASH RAM容量：128KB EEPROM容量：- I/O数量：107 ADC(位数)：12bit DAC(位数)：12bit 振荡器类型：内置 工作电压：1.71V~3.6V 工作温度：-40℃~+85℃ | 单片机/微控制器 | C730119 | https://item.szlcsc.com/778074.html | 现货 | 4小时内发货 | 1 | 540 | 2 | 1 | 106.01 | 0 | 106.01
 |  |  | I | C1349134 |  |  |  | 40 | U2 | 1 |  |  | 无法匹配 |  |  |  |  |  |  |  |  |  |  |  |  |  |  |  | 系统匹配 | IS61WV204816BLL 10TLI | IS61WV204816BLL-10TLI | ISSI(美国芯成) | TSOPI-48 | 存储容量：32Mbit 工作电压：2.4V~3.6V 读写时间：10ns 工作温度：-40℃~+85℃ 工作电流：100mA 待机电流：60mA 功能特性：自动掉电功能 | 存储器 | C1349134 | https://item.szlcsc.com/1439417.html | 现货 | 4小时内发货 | 1 | 96 | 601 | 1 | 176.16 | 0 | 176.16
ADG704BRMZ | ADI(亚德诺) | TSSOP-10_3x3mm_P0.5mm | ADG704BRMZ | C579087 |  |  |  | 41 | U3 | 1 |  |  | 系统匹配 | 低电压4欧姆,4通道多路复用器 | MSOP-10 | 开关电路:4:1 通道数:1 导通电阻(Ron):4.5Ω 工作电压:1.8V~5.5V 导通电容(Con):54pF 导通时间(ton):20ns 关闭时间(toff):13ns 带宽:200MHz 工作温度:-40℃~+85℃ 传播延迟(tpd):- 功能特性:双向模拟通道;无毛刺切换 | 通信接口芯片 | https://item.szlcsc.com/606864.html | 现货 | 4小时内发货 | 1 | 50 | 468 | 1 | 10.6 | 0 | 10.60 |  | 系统匹配 | 低电压4欧姆,4通道多路复用器 | ADG704BRMZ | ADI(亚德诺) | MSOP-10 | 开关电路：4:1 通道数：1 导通电阻(Ron)：4.5Ω 工作电压：1.8V~5.5V 导通电容(Con)：54pF 导通时间(ton)：20ns 关闭时间(toff)：13ns 带宽：200MHz 工作温度：-40℃~+85℃ 传播延迟(tpd)：- 功能特性：双向模拟通道；无毛刺切换 | 通信接口芯片 | C579087 | https://item.szlcsc.com/606864.html | 现货 | 4小时内发货 | 1 | 50 | 468 | 1 | 10.6 | 0 | 10.60
INA828ID | TI(德州仪器) | SOIC-8_3.9x4.9mm_P1.27mm | INA828 | C2859700 |  |  |  | 42 | U4, U7, U11, U14, U16, U20, U21, U22 | 8 |  |  | 人工匹配 | INA828ID | SOIC-8 | 放大器数:单路 输入偏置电流(Ib):150pA 输入失调电压(Vos):20uV 增益带宽积(GBP):- 压摆率(SR):1.2V/us 工作温度:-40℃~+125℃ 功能特性:外部电阻增益;过压保护;EMI滤波/RF抑制 | 运算放大器/比较器 | https://item.szlcsc.com/3064377.html | 现货 | 4小时内发货 | 1 | 75 | 50 | 8 | 7.26 | 0 | 58.08 |  | 系统匹配 | INA828ID | INA828ID | TI(德州仪器) | SOIC-8 | 放大器数：单路 输入偏置电流(Ib)：150pA 输入失调电压(Vos)：20uV 增益带宽积(GBP)：- 压摆率(SR)：1.2V/us 工作温度：-40℃~+125℃ 功能特性：外部电阻增益；过压保护；EMI滤波/RF抑制 | 运算放大器/比较器 | C2859700 | https://item.szlcsc.com/3064377.html | 现货 | 4小时内发货 | 1 | 75 | 50 | 8 | 7.26 | 0 | 58.08
OPA2192IDR | TI(德州仪器) | SOIC-8_3.9x4.9mm_P1.27mm | OPA2192 | C110074 |  |  |  | 43 | U5, U6, U12, U13, U24, U25, U26, U27 | 8 |  |  | 人工匹配 | 36V、精密、轨到轨输入/输出、低失调电压、低输入偏置电流、带e-trim技术的运算放大器 | SOIC-8 | 放大器数:双路 单电源电压:4.5V~36V 双电源(Vee~Vcc):-18V~-2.25V;2.25V~18V 输入失调电压(Vos):5uV 输入失调电压温漂(Vos TC):200nV/℃ 增益带宽积(GBW):10MHz 轨到轨:轨到轨输入,轨到轨输出 压摆率(SR):20V/us 共模抑制比(CMRR):140dB 输入电压噪声密度(eN):5.5nV/√Hz@1kHz 输入偏置电流(Ib):5pA 静态电流(Iq):1mA 输出电流:65mA 输入失调电流(Ios):2pA 工作温度:-40℃~+125℃ 功能特性:EMI滤波/RF抑制;零漂移/自动稳零 | 运算放大器/比较器 | https://item.szlcsc.com/111295.html | 现货 | 4小时内发货 | 1 | 2500 | 42250 | 8 | 7.29 | 0 | 58.32 |  | 系统匹配 | 36V、精密、轨到轨输入/输出、低失调电压、低输入偏置电流、带e-trim技术的运算放大器 | OPA2192IDR | TI(德州仪器) | SOIC-8 | 放大器数：双路 单电源电压：4.5V~36V 双电源(Vee~Vcc)：-18V~-2.25V；2.25V~18V 输入失调电压(Vos)：5uV 输入失调电压温漂(Vos TC)：200nV/℃ 增益带宽积(GBW)：10MHz 轨到轨：轨到轨输入,轨到轨输出 压摆率(SR)：20V/us 共模抑制比(CMRR)：140dB 输入电压噪声密度(eN)：5.5nV/√Hz@1kHz 输入偏置电流(Ib)：5pA 静态电流(Iq)：1mA 输出电流：65mA 输入失调电流(Ios)：2pA 工作温度：-40℃~+125℃ 功能特性：EMI滤波/RF抑制；零漂移/自动稳零 | 运算放大器/比较器 | C110074 | https://item.szlcsc.com/111295.html | 现货 | 4小时内发货 | 1 | 2500 | 42250 | 8 | 7.29 | 0 | 58.32
SGM2059-ADJXN5G/TR | SGMICRO(圣邦微) | SOT-23-5 | SGM2059 | C5152783 |  |  |  | 44 | U8, U15, U17, U23, U35 | 5 |  |  | 人工匹配 | 793mV~5V 300mA 5.5V | SOT-23-5 | 输出极性:正极 工作电压:5.5V 输出电压:793mV~5V 输出电流:300mA 电源纹波抑制比(PSRR):92dB@(1kHz) 压差:72mV@(300mA) 静态电流(Iq):13uA 噪声:9.5uVrms 功能特性:短路保护;使能控制;过流保护;反极性电流保护;输出放电;热关断 工作温度:-40℃~+125℃ 输出类型:可调 输出通道数:1 | 电源管理 | https://item.szlcsc.com/5779511.html | 现货 | 4小时内发货 | 5 | 3000 | 5845 | 5 | 2.03 | 0 | 10.15 |  | 系统匹配 | 793mV~5V 300mA 5.5V | SGM2059-ADJXN5G/TR | SGMICRO(圣邦微) | SOT-23-5 | 输出极性：正极 工作电压：5.5V 输出电压：793mV~5V 输出电流：300mA 电源纹波抑制比(PSRR)：92dB@(1kHz) 压差：72mV@(300mA) 静态电流(Iq)：13uA 噪声：9.5uVrms 功能特性：短路保护；使能控制；过流保护；反极性电流保护；输出放电；热关断 工作温度：-40℃~+125℃ 输出类型：可调 输出通道数：1 | 电源管理 | C5152783 | https://item.szlcsc.com/5779511.html | 现货 | 4小时内发货 | 5 | 3000 | 5845 | 5 | 2.03 | 0 | 10.15
ADG619 |  | SOT-23-8 |  | C88062 |  |  |  | 45 | U9, U10, U18, U19 | 4 |  |  | 无法匹配 |  |  |  |  |  |  |  |  |  |  |  |  |  |  |  | 系统匹配 | CMOS单刀双掷开关 | ADG619BRTZ-REEL7 | ADI(亚德诺) | SOT-23-8 | 开关电路：2:1 通道数：1 导通电阻(Ron)：4Ω 工作电压：2.7V~5.5V；-5.5V~-2.7V 导通电容(Con)：95pF 导通时间(ton)：120ns 关闭时间(toff)：110ns 带宽：190MHz 工作温度：-40℃~+85℃ 传播延迟(tpd)：- 功能特性：双向模拟通道；无毛刺切换 | 通信接口芯片 | C88062 | https://item.szlcsc.com/89240.html | 现货 | 4小时内发货 | 1 | 3000 | 3800 | 4 | 14.96 | 0 | 59.84
OPA197 |  | SOT-23-5 |  | C221351 |  |  |  | 46 | U28 | 1 |  |  | 无法匹配 |  |  |  |  |  |  |  |  |  |  |  |  |  |  |  | 系统匹配 | 36V精密、轨到轨输入/输出、低失调电压运算放大器 | OPA197IDBVR | TI(德州仪器) | SOT-23-5 | 放大器数：1 最大电源宽度(Vdd-Vss)：36V 轨到轨：轨到轨输入,轨到轨输出 增益带宽积(GBW)：10MHz 输入失调电压(Vos)：100uV 输入失调电压温漂(Vos TC)：2.5uV/℃ 压摆率(SR)：20V/us 输入偏置电流(Ib)：5pA 输入失调电流(Ios)：20pA 输入电压噪声密度(eN)：5.5nV/√Hz@1kHz 共模抑制比(CMRR)：140dB 输入失调电流温漂(Ios TC)：- 静态电流(Iq)：1mA 输出电流：65mA 工作温度：-40℃~+125℃ 单电源电压：4.5V~36V 双电源电压(Vee~Vcc)：2.25V~18V；-18V~-2.25V 功能特性：EMI滤波/RF抑制 | 运算放大器/比较器 | C221351 | https://item.szlcsc.com/221743.html | 现货 | 4小时内发货 | 1 | 3000 | 4 | 1 | 6.06 | 0 | 6.06
SN74LVC1G07DBVR | TI(德州仪器) | SOT-23-5 | 74LVC1G07 | C7829 |  |  |  | 47 | U29 | 1 |  |  | 人工匹配 | 单路缓冲器/驱动器,漏极开路输出 | SOT-23-5 | 输入类型:- 输出类型:开漏 工作电压:1.65V~5.5V 元件数:1 每个元件位数:1 通道类型:单向 灌电流(IOL):32mA 拉电流(IOH):- 系列:74LVC 工作温度:-40℃~+125℃ 静态电流(Iq):10uA 传播延迟(tpd):4.2ns@3.3V,50pF 功能特性:掉电隔离;电平转换 | 逻辑器件 | https://item.szlcsc.com/8306.html | 现货 | 4小时内发货 | 5 | 3000 | 4440 | 5 | 0.5591 | 0 | 2.80 |  | 系统匹配 | 单路缓冲器/驱动器，漏极开路输出 | SN74LVC1G07DBVR | TI(德州仪器) | SOT-23-5 | 输入类型：- 输出类型：开漏 工作电压：1.65V~5.5V 元件数：1 每个元件位数：1 通道类型：单向 灌电流(IOL)：32mA 拉电流(IOH)：- 系列：74LVC 工作温度：-40℃~+125℃ 静态电流(Iq)：10uA 传播延迟(tpd)：4.2ns@3.3V,50pF 功能特性：掉电隔离；电平转换 | 逻辑器件 | C7829 | https://item.szlcsc.com/8306.html | 现货 | 4小时内发货 | 5 | 3000 | 4440 | 5 | 0.5591 | 0 | 2.80
 |  | SOIC-8 |  | C2832998 |  |  |  | 48 | U30 | 1 |  |  | 无法匹配 |  |  |  |  |  |  |  |  |  |  |  |  |  |  |  | 系统匹配 | 双路和四路串行闪存 | GD25Q32ESIGR | GigaDevice(兆易创新) | SOP-8-208mil | 接口类型：SPI 存储容量：32Mbit 时钟频率(fc)：133MHz 工作电压：2.7V~3.6V 待机电流：12uA 擦写寿命：100000次 页写入时间(Tpp)：500us 块擦除时间(tBE)：150ms@(32KB) 数据保留 - TDR(年)：20年 工作温度：- 功能特性：硬件写保护；绝对写保护；写使能锁存；软件写保护 | 存储器 | C2832998 | https://item.szlcsc.com/2992372.html | 现货 | 4小时内发货 | 1 | 2000 | 39079 | 1 | 5.57 | 0 | 5.57
SGM3204YN6G/TR | SGMICRO(圣邦微) | SOT-23-6 | SGM3204 | C194031 |  |  |  | 49 | U31 | 1 |  |  | 人工匹配 | 非稳压200mA电荷泵电压反相器 | SOT-23-6 | 功能类型:反相 工作电压:1.4V~5.5V 输出电流(Iout):200mA 静态电流(Iq):1.84mA 输出电阻:4.2Ω 能量效率:80% 开关频率:950kHz 工作温度:-40℃~+85℃ 功能特性:低功耗待机 | 电源管理 | https://item.szlcsc.com/234001.html | 现货 | 4小时内发货 | 1 | 3000 | 9324 | 1 | 7.84 | 0 | 7.84 |  | 系统匹配 | 非稳压200mA电荷泵电压反相器 | SGM3204YN6G/TR | SGMICRO(圣邦微) | SOT-23-6 | 功能类型：反相 工作电压：1.4V~5.5V 输出电流(Iout)：200mA 静态电流(Iq)：1.84mA 输出电阻：4.2Ω 能量效率：80% 开关频率：950kHz 工作温度：-40℃~+85℃ 功能特性：低功耗待机 | 电源管理 | C194031 | https://item.szlcsc.com/234001.html | 现货 | 4小时内发货 | 1 | 3000 | 9324 | 1 | 7.84 | 0 | 7.84
 | Texas | 5x5mm |  | C90084 |  |  |  | 50 | U32 | 1 |  |  | 无法匹配 |  |  |  |  |  |  |  |  |  |  |  |  |  |  |  | 系统匹配 | 1.4V~34V 1A 35V | TPS7A4701RGWR | TI(德州仪器) | VQFN-20-EP(5x5) | 输出极性：正极 工作电压：35V 输出电压：1.4V~34V 输出电流：1A 电源纹波抑制比(PSRR)：78dB@(1kHz) 压差：307mV@(1A) 静态电流(Iq)：- 噪声：4uVrms 功能特性：使能控制；过流保护；噪声旁路端子；内置软启动；热关断；输入欠压保护 工作温度：-40℃~+125℃@(Tj) 输出类型：可调 输出通道数：1 | 电源管理 | C90084 | https://item.szlcsc.com/91269.html | 现货 | 4小时内发货 | 1 | 3000 | 10 | 1 | 15.53 | 0 | 15.53
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

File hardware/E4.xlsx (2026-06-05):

编号 | 位号 | 封装 | 数量 | 名称 | 供应商编号 | 价格
1 | C1, C2 | C_0603_1608Metric | 2 | 10pF
2 | C3, C17 | C_0603_1608Metric | 2 | 4.7uF
3 | C4, C5, C6, C7, C8, C9, C10, C11, C13, C15, C16, C18, C19, C45, C46, C48, C49, C50, C51, C52, C53, C54, C55, C56, C57, C71, C73, C75, C77, C78, C79, C80, C82, C86, C98, C100, C103, C104, C106, C109, C110, C111, C112, C113, C114, C115, C116, C117, C118, C120, C121, C122, C123, C145, C147, C156, C158, C159, C161, C169, C170 | C_0603_1608Metric | 61 | 100nF
4 | C12, C14, C27, C28, C33, C34, C126, C127, C131, C132, C136, C137, C138, C139, C140, C141, C142, C143, C166, C167 | C_0603_1608Metric | 20 | 1uF
5 | C20, C30, C40, C41 | C_0603_1608Metric | 4 | 120pF
6 | C21, C22, C24, C25, C26, C29, C31, C35, C36, C37, C38, C39, C42, C43, C128, C129, C130, C133, C134, C135 | C_0603_1608Metric | 20 | 100pF
7 | C23, C32, C124, C125 | C_0603_1608Metric | 4 | 750pF
8 | C44, C47, C58, C59, C60, C61, C62, C63, C64, C65, C66, C67, C68, C69, C70, C72, C74, C76, C81, C83, C84, C85, C87, C88, C89, C90, C91, C92, C93, C94, C95, C96, C97, C99, C101, C102, C105, C107, C108, C119, C144, C146, C152, C153, C155, C157, C160, C162 | C_0603_1608Metric | 48 | 10uF
9 | C148, C149, C150 | C_0603_1608Metric | 3 | 3.3uF
10 | C151, C154 | C_1206_3216Metric | 2 | 47uF
11 | D1 | SOT-143 | 1 | PRTR5V0U2X
12 | J1 | PinHeader_1x03_P1.00mm_Vertical | 1 | Conn_01x03_Pin
13 | J2, J3, J4, J5 | RJ45_Amphenol_54602-x08_Horizontal | 4 | RJ45
14 | J6 | USB_A_CUI_UJ2-ADH-TH_Horizontal_Stacked | 1 | USB_A_Stacked
15 | J7 | BarrelJack_Kycon_KLDX-0202-xC_Horizontal | 1 | Barrel_Jack_Switch
16 | R1, R2, R65, R66, R68 | R_0603_1608Metric | 5 | 10kR
17 | R3, R4, R12, R14, R18, R19, R26, R28, R34, R35, R36, R37, R52, R54, R61, R62 | R_0603_1608Metric | 16 | 1kR
18 | R5, R20, R39, R40 | R_0603_1608Metric | 4 | 120R
19 | R6, R22, R45, R46 | R_0603_1608Metric | 4 | 8.45kR
20 | R7, R21, R42, R44 | R_0603_1608Metric | 4 | 6.19kR
21 | R8, R23, R47, R48 | R_0603_1608Metric | 4 | 2.15kR
22 | R9, R24, R49, R50 | R_0603_1608Metric | 4 | 3.92kR
23 | R10, R27, R57, R58 | R_0603_1608Metric | 4 | 8kR
24 | R11, R25, R51, R53 | R_0603_1608Metric | 4 | 7kR
25 | R13, R31, R33, R41 | R_0603_1608Metric | 4 | 26.7kR
26 | R15, R16, R29, R30, R55, R56, R59, R60 | R_0603_1608Metric | 8 | 49.9R
27 | R17, R32, R38, R43 | R_0603_1608Metric | 4 | 12.4kR
28 | R63 | R_0603_1608Metric | 1 | 39kR
29 | R64 | R_0603_1608Metric | 1 | 20kR
30 | R67 | R_0603_1608Metric | 1 | 24kR
31 | R69 | R_0603_1608Metric | 1 | 47kR
32 | R70 | R_0603_1608Metric | 1 | 15kR
33 | SW1 | SW_SPST_FSMSM | 1 | SW_MEC_5G
34 | SW2 | SW-TH_G-SWITCH-PS-22F03N | 1 | PS-22F02
35 | U1 | LQFP-128_14x14mm_P0.4mm | 1 | STM32G473QETxZ
36 | U2 | TSOP-I-48_18.4x12mm_P0.5mm | 1 | IS61W204816BLL
37 | U3 | TSSOP-10_3x3mm_P0.5mm | 1 | ADG704BRMZ
38 | U4, U7, U11, U14, U16, U20, U21, U22 | Infineon_PG-DSO-8-43 | 8 | INA828
39 | U5, U6, U12, U13, U24, U25, U26, U27 | SOIC-8_3.9x4.9mm_P1.27mm | 8 | OPA2192
40 | U8, U15, U17, U23, U35 | SOT-23-5 | 5 | SGM2059
41 | U9, U10, U18, U19 | SOT-23-8 | 4 | ADG719
42 | U28 | SOT-23-5 | 1 | OPA197xDBV
43 | U29 | SOT-23-5 | 1 | 74LVC1G07
44 | U30 | SOIC-8_5.3x5.3mm_P1.27mm | 1 | GD25Q32JVSS
45 | U31 | SOT-23-6 | 1 | SGM3204
46 | U32 | Texas_RGW0020A_VQFN-20-1EP_5x5mm_P0.65mm_EP3.15x3.15mm_ThermalVias | 1 | TPS7A4701xRGW
47 | U33 | Texas_RGW0020A_VQFN-20-1EP_5x5mm_P0.65mm_EP3.15x3.15mm_ThermalVias | 1 | TPS7A3301RGW
48 | U34 | SOT-223-3_TabPin2 | 1 | AMS1117-3.3
49 | Y1 | Crystal_SMD_3225-4Pin_3.2x2.5mm | 1 | 25MHz

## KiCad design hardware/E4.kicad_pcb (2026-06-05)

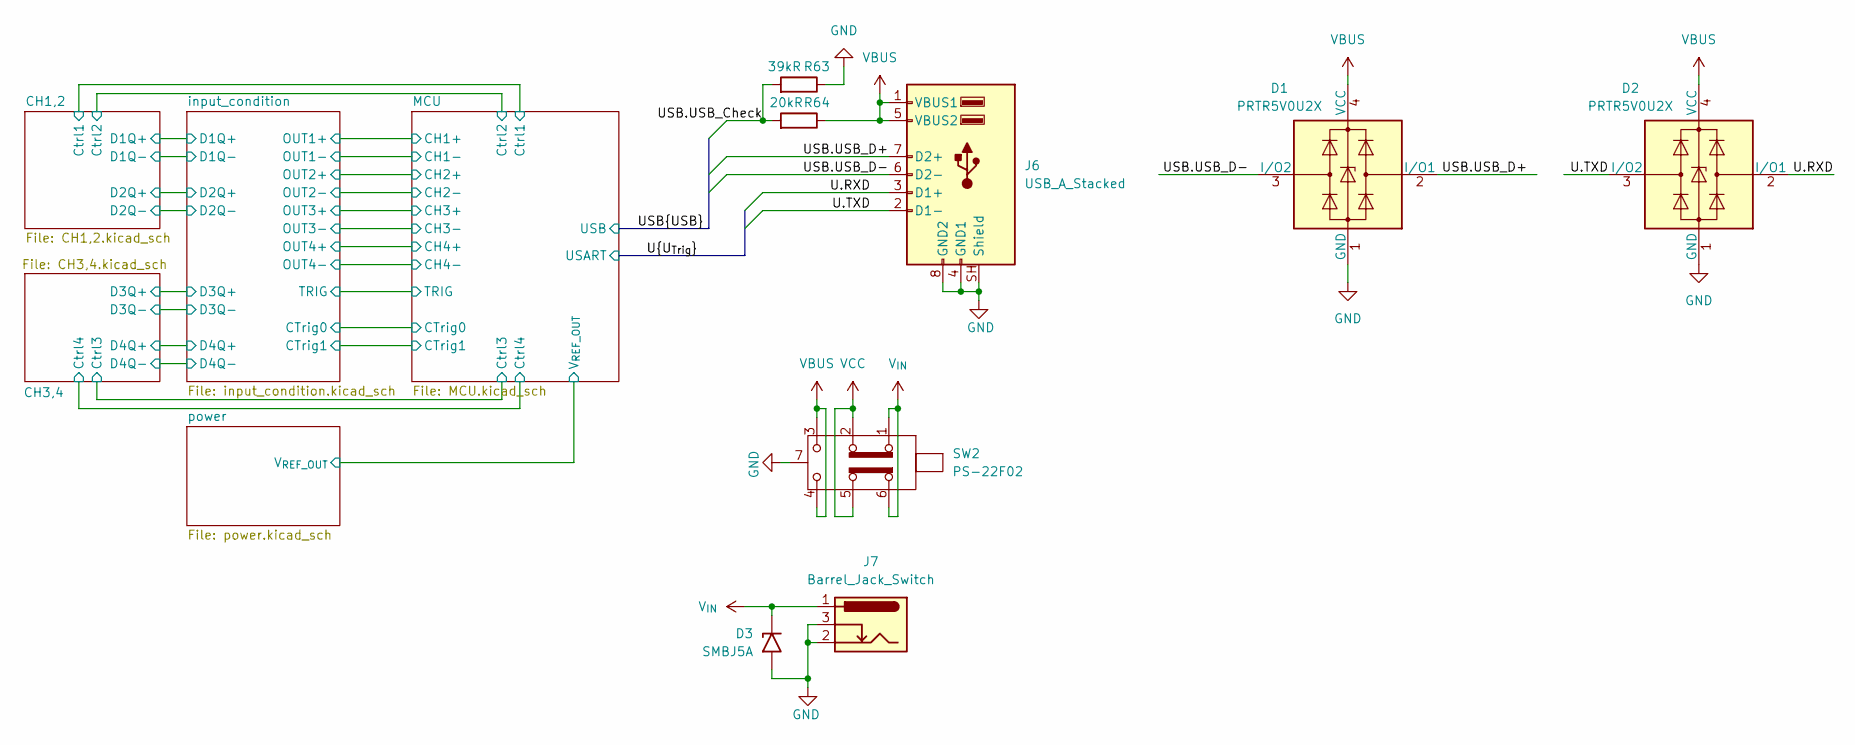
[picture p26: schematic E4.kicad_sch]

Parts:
D1, D2: PRTR5V0U2X; SOT-143
D3: SMBJ5A; D_SMF
J6: USB_A_Stacked; USB_A_CUI_UJ2-ADH-TH_Horizontal_Stacked
J7: Barrel_Jack_Switch; BarrelJack_Kycon_KLDX-0202-xC_Horizontal
R63: 39kR; R_0603_1608Metric
R64: 20kR; R_0603_1608Metric
SW2: PS-22F02; SW-TH_G-SWITCH-PS-22F03N

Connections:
/U.RXD: D2.2 (I/O1), J6.3 (D1+); also elsewhere on the board
/U.TXD: D2.3 (I/O2), J6.2 (D1-); also elsewhere on the board
/USB.USB_Check: R63.2, R64.2; also elsewhere on the board
/USB.USB_D+: D1.2 (I/O1), J6.7 (D2+); also elsewhere on the board
/USB.USB_D-: D1.3 (I/O2), J6.6 (D2-); also elsewhere on the board
GND: D1.1 (GND), D2.1 (GND), D3.2 (A2), J6.4 (GND1), J6.8 (GND2), J6.SH (Shield), J7.2, J7.3, R63.1, SW2.7, SW2.8; also elsewhere on the board
VBUS: D1.4 (VCC), D2.4 (VCC), J6.1 (VBUS1), J6.5 (VBUS2), R64.1, SW2.3 (C), SW2.4 (A)
VCC: SW2.2 (B), SW2.5 (B); also elsewhere on the board
V_{IN}: D3.1 (A1), J7.1, SW2.1 (A), SW2.6 (C)

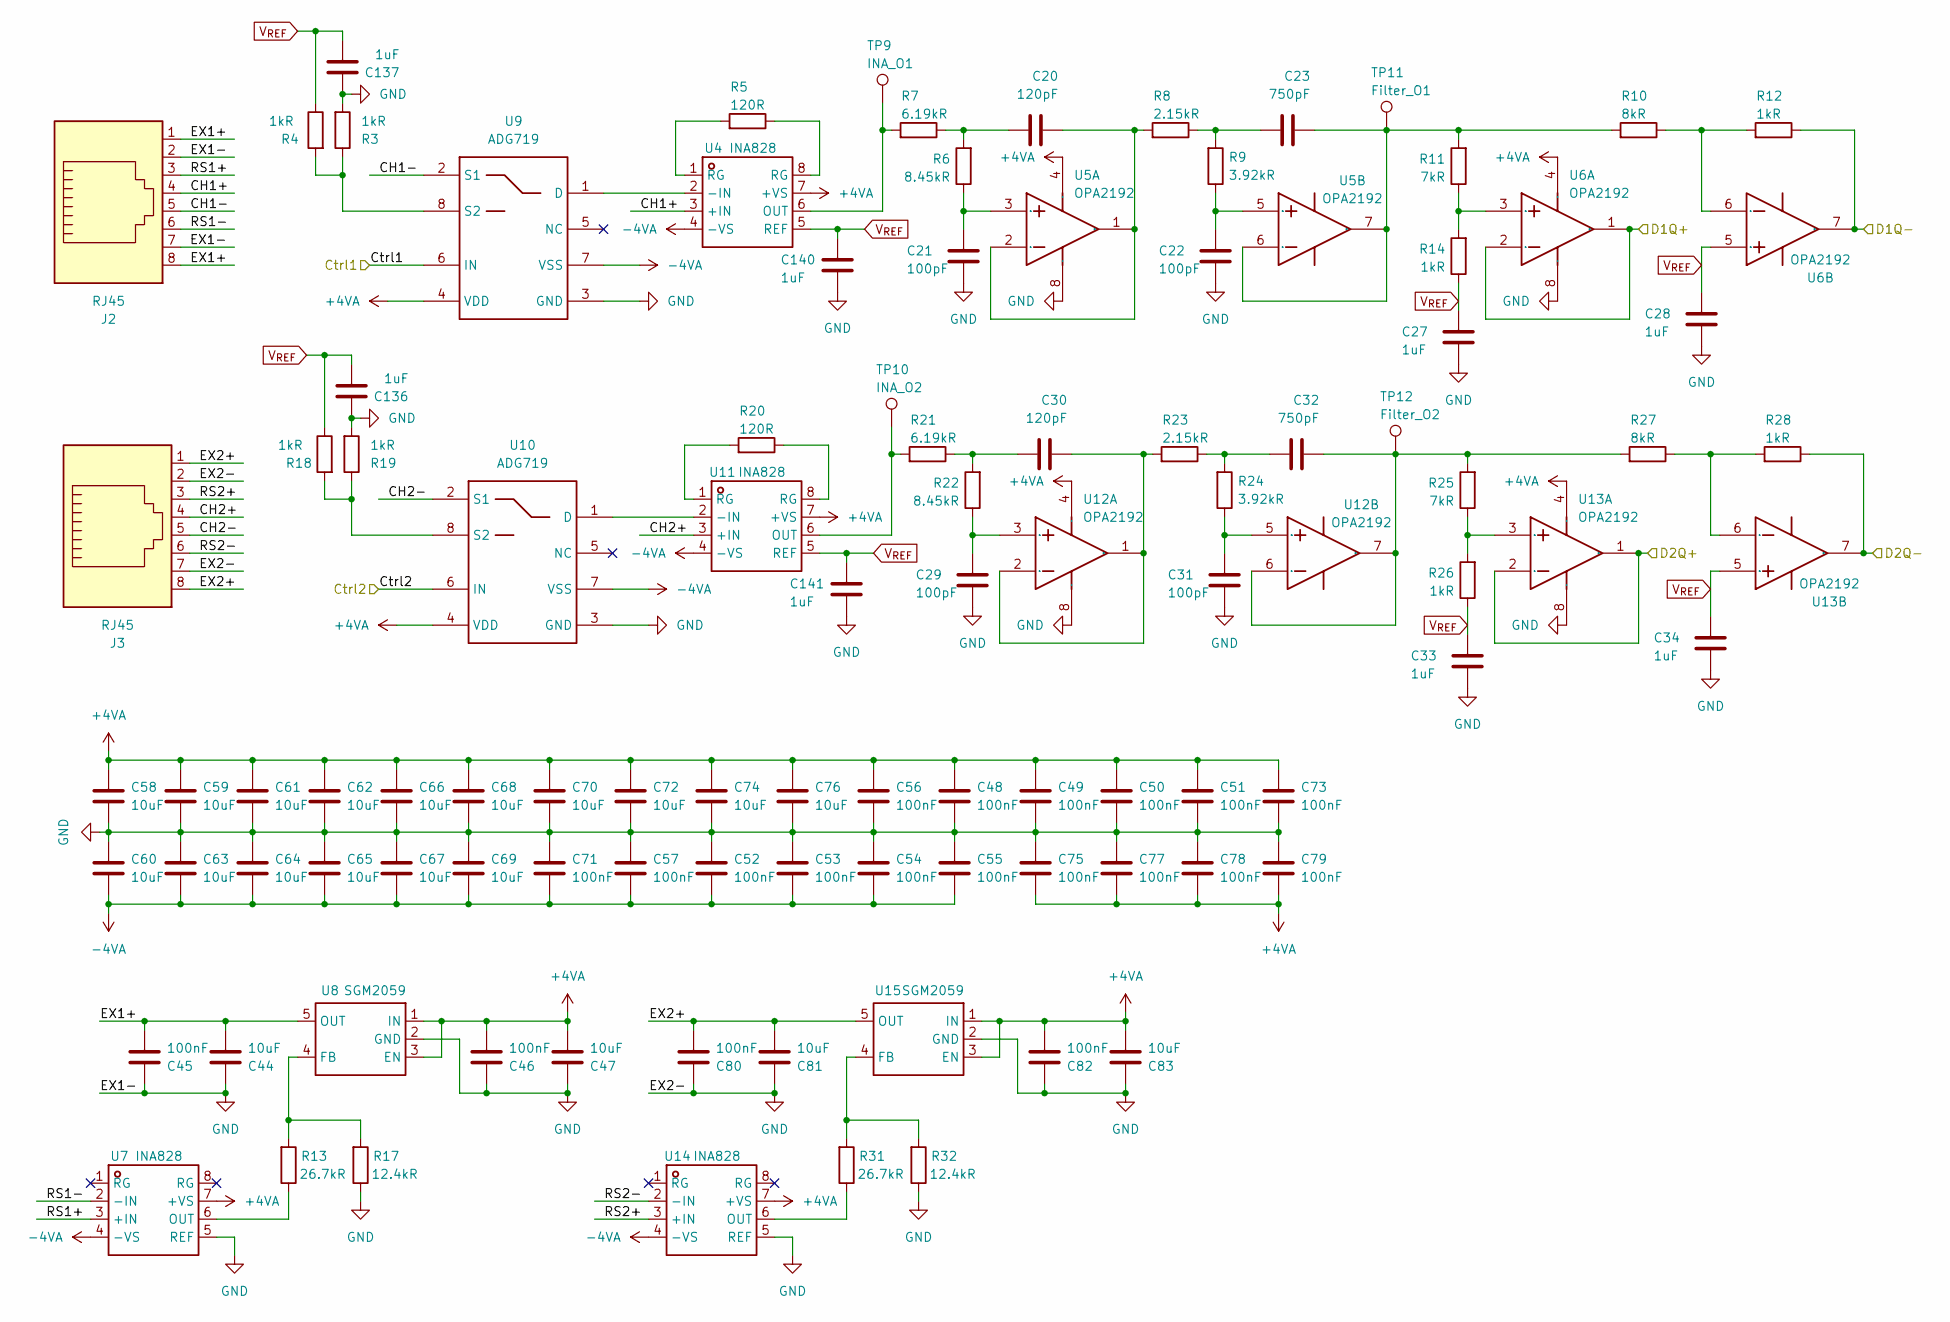
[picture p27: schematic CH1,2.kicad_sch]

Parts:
C20, C30: 120pF; C_0603_1608Metric
C21, C22, C29, C31: 100pF; C_0603_1608Metric
C23, C32: 750pF; C_0603_1608Metric
C27, C28, C33, C34, C136, C137, C140, C141: 1uF; C_0603_1608Metric
C44, C47, C58, C59, C60, C61, C62, C63, C64, C65, C66, C67, C68, C69, C70, C72, C74, C76, C81, C83: 10uF; C_0603_1608Metric
C45, C46, C48, C49, C50, C51, C52, C53, C54, C55, C56, C57, C71, C73, C75, C77, C78, C79, C80, C82: 100nF; C_0603_1608Metric
J2, J3: RJ45; RJ45_Amphenol_54602-x08_Horizontal
R3, R4, R12, R14, R18, R19, R26, R28: 1kR; R_0603_1608Metric
R5, R20: 120R; R_0603_1608Metric
R6, R22: 8.45kR; R_0603_1608Metric
R7, R21: 6.19kR; R_0603_1608Metric
R8, R23: 2.15kR; R_0603_1608Metric
R9, R24: 3.92kR; R_0603_1608Metric
R10, R27: 8kR; R_0603_1608Metric
R11, R25: 7kR; R_0603_1608Metric
R13, R31: 26.7kR; R_0603_1608Metric
R17, R32: 12.4kR; R_0603_1608Metric
TP9: INA_O1; TestPoint_Pad_D1.0mm
TP10: INA_O2; TestPoint_Pad_D1.0mm
TP11: Filter_O1; TestPoint_Pad_D1.0mm
TP12: Filter_O2; TestPoint_Pad_D1.0mm
U4, U7, U11, U14: INA828; SOIC-8_3.9x4.9mm_P1.27mm; Manufacturer Part INA828IDR; LCSC Part Name INA828IDR
U5, U6, U12, U13: OPA2192; SOIC-8_3.9x4.9mm_P1.27mm; Manufacturer Part OPA2192IDR; LCSC Part Name OPA2192IDR
U8, U15: SGM2059; SOT-23-5; Manufacturer Part SGM2059-ADJXN5G/TR; LCSC Part Name 300mA，低输入电压、超低噪声、高电源抑制比线性稳压器
U9, U10: ADG719; SOT-23-8; Manufacturer Part ADG619BRTZ-REEL7; LCSC Part Name CMOS单刀双掷开关

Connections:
+4VA: C46.2, C47.2, C48.2, C49.2, C50.2, C51.2, C56.2, C58.1, C59.1, C61.1, C62.1, C66.1, C68.1, C70.1, C72.1, C73.2, C74.1, C75.1, C76.1, C77.1, C78.1, C79.1, C82.2, C83.2, U4.7 (+VS), U5.4 (VSS), U6.4 (VSS), U7.7 (+VS), U8.1 (IN), U8.3 (EN), U9.4 (VDD), U10.4 (VDD), U11.7 (+VS), U12.4 (VSS), U13.4 (VSS), U14.7 (+VS), U15.1 (IN), U15.3 (EN); also elsewhere on the board
-4VA: C52.1, C53.1, C54.1, C55.1, C57.1, C60.2, C63.2, C64.2, C65.2, C67.2, C69.2, C71.1, U4.4 (-VS), U7.4 (-VS), U9.7 (VSS), U10.7 (VSS), U11.4 (-VS), U14.4 (-VS); also elsewhere on the board
/CH1,2/CH1+: J2.4, U4.3 (+IN)
/CH1,2/CH1-: J2.5, U9.2 (S1)
/CH1,2/CH2+: J3.4, U11.3 (+IN)
/CH1,2/CH2-: J3.5, U10.2 (S1)
/CH1,2/Ctrl1: U9.6 (IN); also elsewhere on the board
/CH1,2/Ctrl2: U10.6 (IN); also elsewhere on the board
/CH1,2/D1Q+: U6.1 (VOUTA), U6.2 (VINA-); also elsewhere on the board
/CH1,2/D1Q-: R12.1, U6.7 (VOUTB); also elsewhere on the board
/CH1,2/D2Q+: U13.1 (VOUTA), U13.2 (VINA-); also elsewhere on the board
/CH1,2/D2Q-: R28.1, U13.7 (VOUTB); also elsewhere on the board
/CH1,2/EX1+: C44.2, C45.2, J2.1, J2.8, U8.5 (OUT)
/CH1,2/EX2+: C80.2, C81.2, J3.1, J3.8, U15.5 (OUT)
/CH1,2/RS1+: J2.3, U7.3 (+IN)
/CH1,2/RS1-: J2.6, U7.2 (-IN)
/CH1,2/RS2+: J3.3, U14.3 (+IN)
/CH1,2/RS2-: J3.6, U14.2 (-IN)
GND: C21.2, C22.2, C27.2, C28.2, C29.2, C31.2, C33.2, C34.2, C44.1, C45.1, C46.1, C47.1, C48.1, C49.1, C50.1, C51.1, C52.2, C53.2, C54.2, C55.2, C56.1, C57.2, C58.2, C59.2, C60.1, C61.2, C62.2, C63.1, C64.1, C65.1, C66.2, C67.1, C68.2, C69.1, C70.2, C71.2, C72.2, C73.1, C74.2, C75.2, C76.2, C77.2, C78.2, C79.2, C80.1, C81.1, C82.1, C83.1, C136.1, C137.1, C140.2, C141.2, J2.2, J2.7, J3.2, J3.7, R3.2, R17.1, R19.2, R32.1, U5.8 (VDD), U6.8 (VDD), U7.5 (REF), U8.2 (GND), U9.3 (GND), U10.3 (GND), U12.8 (VDD), U13.8 (VDD), U14.5 (REF), U15.2 (GND); also elsewhere on the board
unnamed: C20.2, R6.2, R7.1
unnamed: C23.2, R8.1, R9.2
unnamed: C30.2, R21.1, R22.2
unnamed: C32.2, R23.1, R24.2
unnamed: R5.1, U4.8 (RG)
unnamed: R5.2, U4.1 (RG)
unnamed: R20.1, U11.8 (RG)
unnamed: R20.2, U11.1 (RG)
unnamed: U4.2 (-IN), U9.1 (D)
unnamed: R7.2, TP9.1 (1_1), U4.6 (OUT)
unnamed: C21.1, R6.1, U5.3 (VINA+)
unnamed: C20.1, R8.2, U5.1 (VOUTA), U5.2 (VINA-)
unnamed: C22.1, R9.1, U5.5 (VINB+)
unnamed: C23.1, R10.2, R11.2, TP11.1 (1_1), U5.6 (VINB-), U5.7 (VOUTB)
unnamed: R11.1, R14.2, U6.3 (VINA+)
unnamed: R10.1, R12.2, U6.6 (VINB-)
unnamed: R13.1, U7.6 (OUT)
unnamed: R13.2, R17.2, U8.4 (FB)
unnamed: R3.1, R4.2, U9.8 (S2)
unnamed: U10.1 (D), U11.2 (-IN)
unnamed: R18.2, R19.1, U10.8 (S2)
unnamed: R21.2, TP10.1 (1_1), U11.6 (OUT)
unnamed: C29.1, R22.1, U12.3 (VINA+)
unnamed: C30.1, R23.2, U12.1 (VOUTA), U12.2 (VINA-)
unnamed: C31.1, R24.1, U12.5 (VINB+)
unnamed: C32.1, R25.2, R27.2, TP12.1 (1_1), U12.6 (VINB-), U12.7 (VOUTB)
unnamed: R25.1, R26.2, U13.3 (VINA+)
unnamed: R27.1, R28.2, U13.6 (VINB-)
unnamed: R31.1, U14.6 (OUT)
unnamed: R31.2, R32.2, U15.4 (FB)
V_{REF}: C27.1, C28.1, C33.1, C34.1, C136.2, C137.2, C140.1, C141.1, R4.1, R14.1, R18.1, R26.1, U4.5 (REF), U6.5 (VINB+), U11.5 (REF), U13.5 (VINB+); also elsewhere on the board

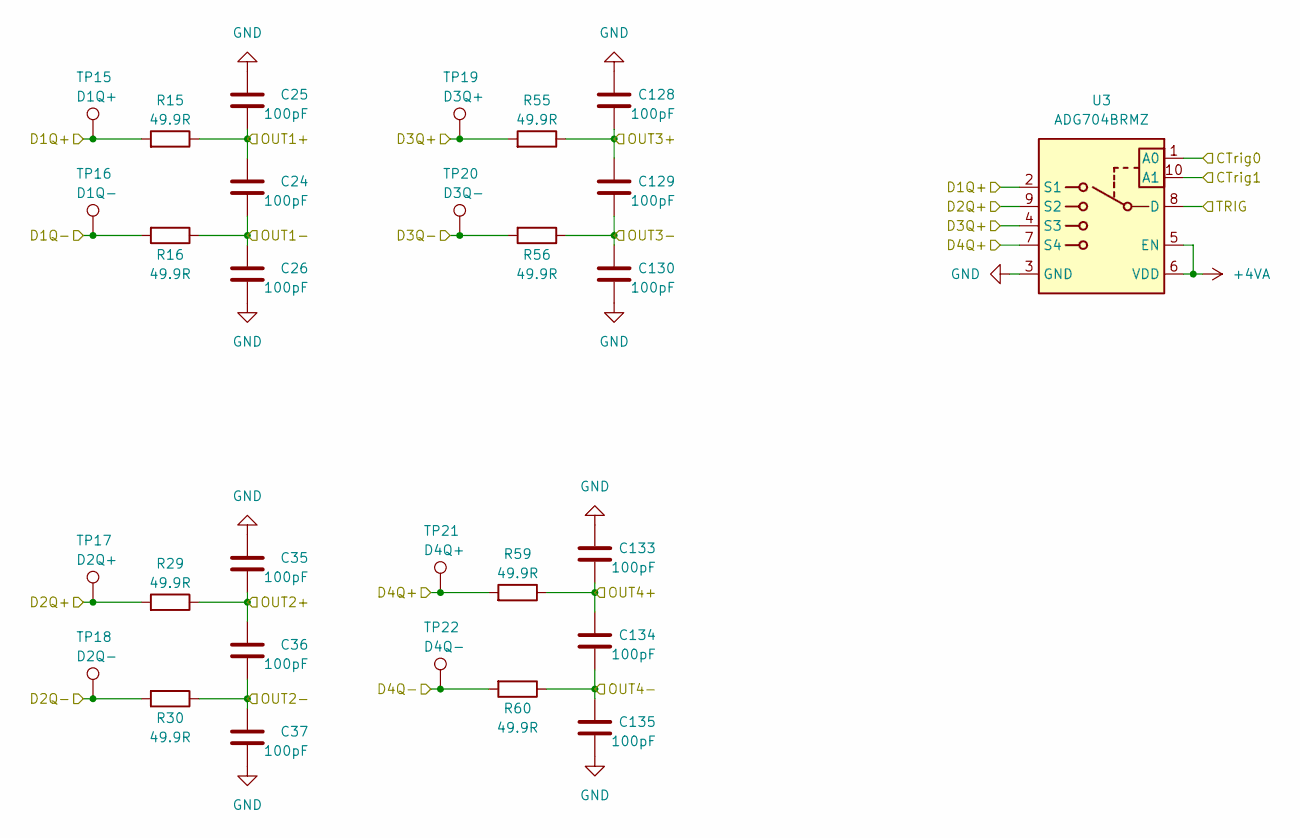
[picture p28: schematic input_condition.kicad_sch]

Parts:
C24, C25, C26, C35, C36, C37, C128, C129, C130, C133, C134, C135: 100pF; C_0402_1005Metric
R15, R16, R29, R30, R55, R56, R59, R60: 49.9R; R_0402_1005Metric
TP15: D1Q+; TestPoint_Pad_D1.0mm
TP16: D1Q-; TestPoint_Pad_D1.0mm
TP17: D2Q+; TestPoint_Pad_D1.0mm
TP18: D2Q-; TestPoint_Pad_D1.0mm
TP19: D3Q+; TestPoint_Pad_D1.0mm
TP20: D3Q-; TestPoint_Pad_D1.0mm
TP21: D4Q+; TestPoint_Pad_D1.0mm
TP22: D4Q-; TestPoint_Pad_D1.0mm
U3: ADG704BRMZ; TSSOP-10_3x3mm_P0.5mm

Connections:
+4VA: U3.5 (EN), U3.6 (VDD); also elsewhere on the board
/CH1,2/D1Q+: R15.2, TP15.1 (1_1), U3.2 (S1); also elsewhere on the board
/CH1,2/D1Q-: R16.2, TP16.1 (1_1); also elsewhere on the board
/CH1,2/D2Q+: R29.2, TP17.1 (1_1), U3.9 (S2); also elsewhere on the board
/CH1,2/D2Q-: R30.2, TP18.1 (1_1); also elsewhere on the board
/CH3,4/D3Q+: R55.2, TP19.1 (1_1), U3.4 (S3); also elsewhere on the board
/CH3,4/D3Q-: R56.2, TP20.1 (1_1); also elsewhere on the board
/CH3,4/D4Q+: R59.2, TP21.1 (1_1), U3.7 (S4); also elsewhere on the board
/CH3,4/D4Q-: R60.2, TP22.1 (1_1); also elsewhere on the board
/MCU/CH1+: C24.1, C25.2, R15.1; also elsewhere on the board
/MCU/CH1-: C24.2, C26.1, R16.1; also elsewhere on the board
/MCU/CH2+: C35.2, C36.1, R29.1; also elsewhere on the board
/MCU/CH2-: C36.2, C37.1, R30.1; also elsewhere on the board
/MCU/CH3+: C128.2, C129.1, R55.1; also elsewhere on the board
/MCU/CH3-: C129.2, C130.1, R56.1; also elsewhere on the board
/MCU/CH4+: C133.2, C134.1, R59.1; also elsewhere on the board
/MCU/CH4-: C134.2, C135.1, R60.1; also elsewhere on the board
/MCU/CTrig0: U3.1 (A0); also elsewhere on the board
/MCU/CTrig1: U3.10 (A1); also elsewhere on the board
/MCU/TRIG: U3.8 (D); also elsewhere on the board
GND: C25.1, C26.2, C35.1, C37.2, C128.1, C130.2, C133.1, C135.2, U3.3 (GND); also elsewhere on the board

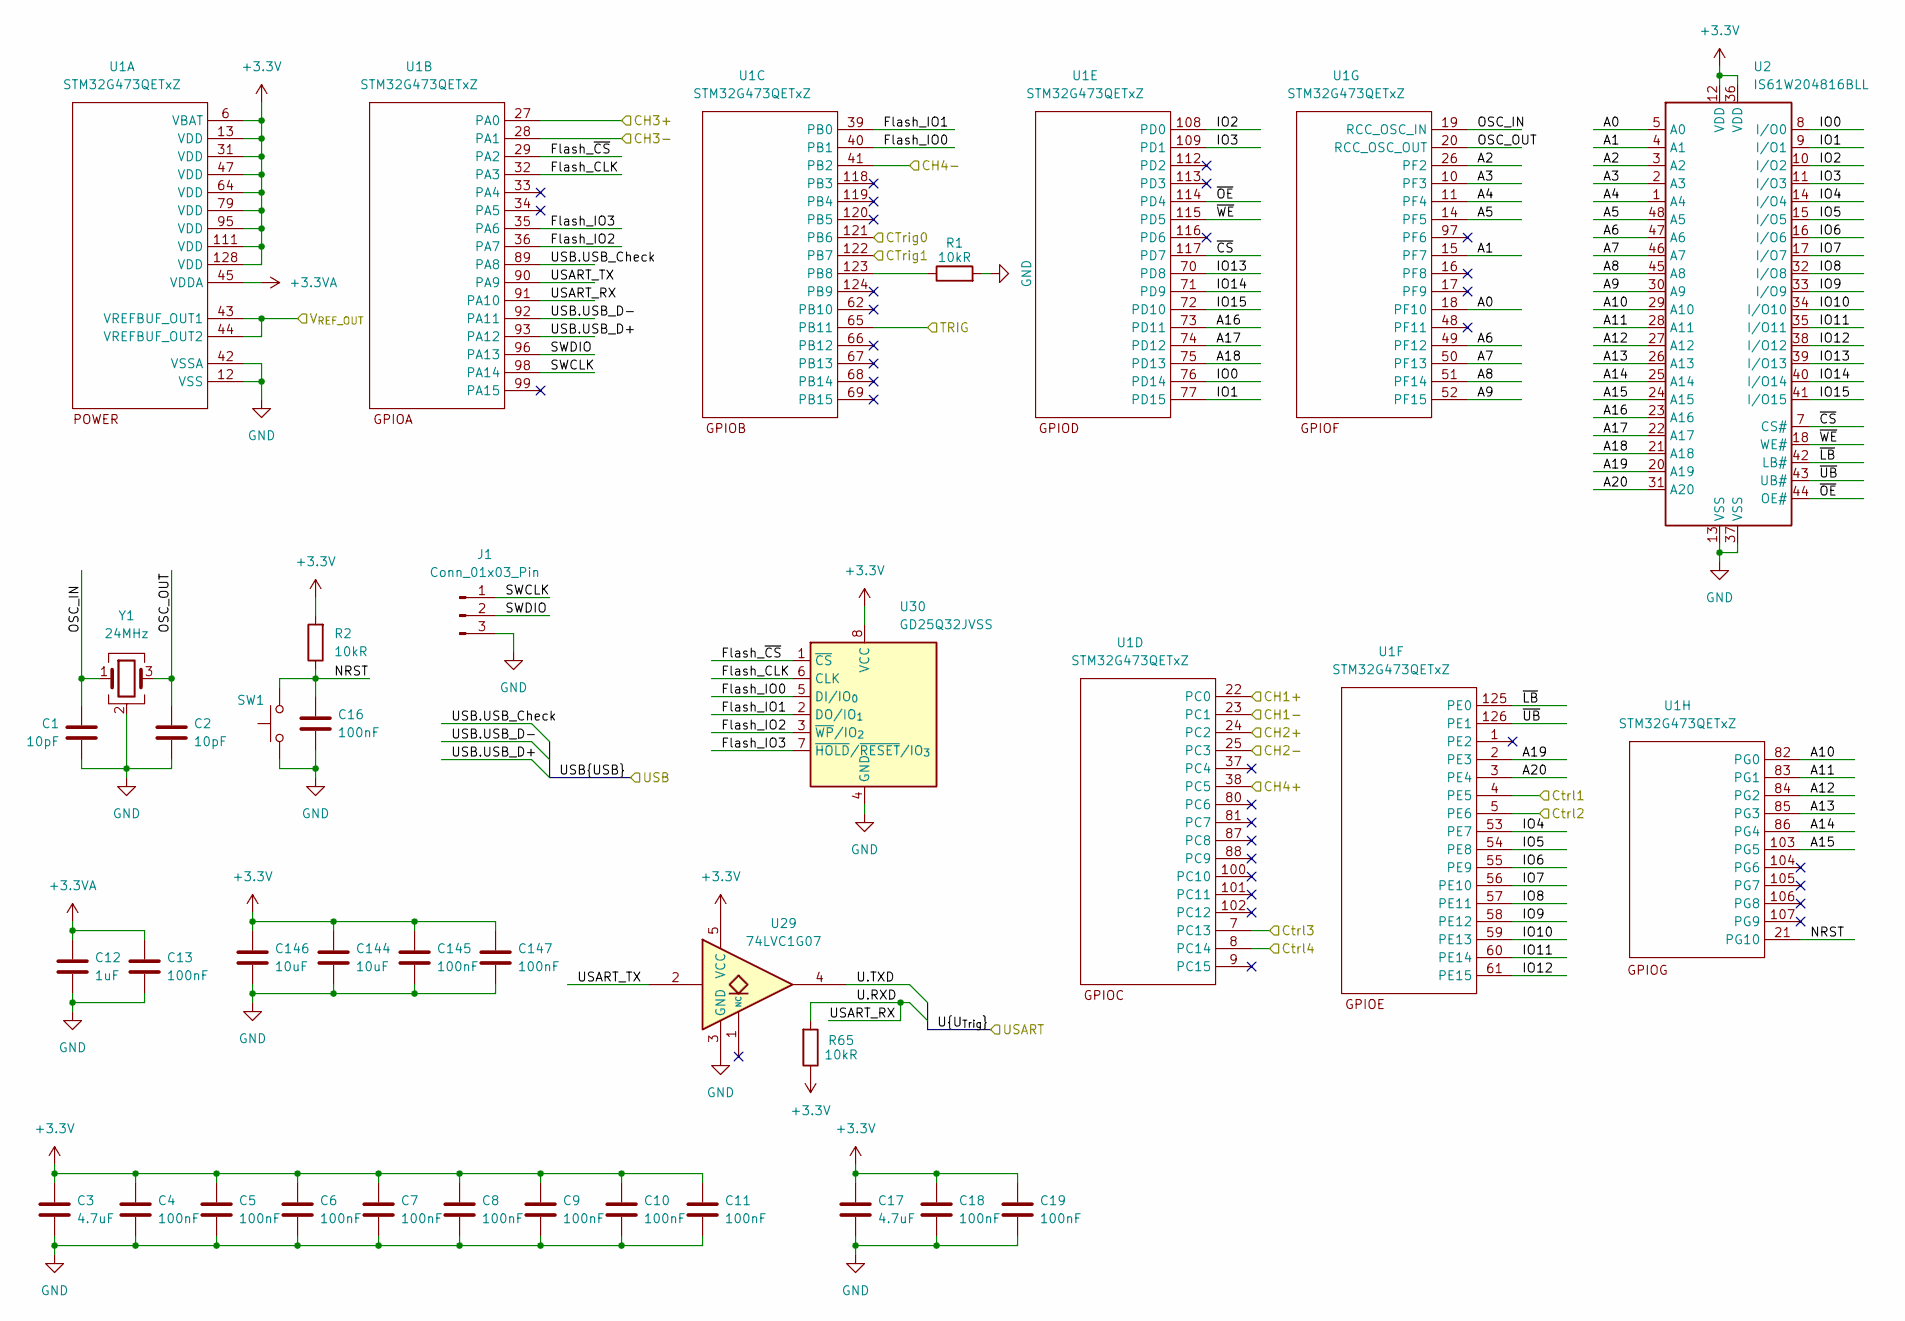
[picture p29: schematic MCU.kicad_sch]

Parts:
C1, C2: 10pF; C_0402_1005Metric
C3, C17: 4.7uF; C_0603_1608Metric
C4, C13: 100nF; C_0402_1005Metric
C5, C6, C7, C8, C9, C10, C11, C16, C18, C19, C145, C147: 100nF; C_0603_1608Metric
C12: 1uF; C_0402_1005Metric
C144, C146: 10uF; C_0603_1608Metric
J1: Conn_01x03_Pin; PinHeader_1x03_P1.00mm_Vertical
R1, R2, R65: 10kR; R_0603_1608Metric
SW1: SW_MEC_5G; SW_SPST_FSMSM
U1: STM32G473QETxZ; LQFP-128_14x14mm_P0.4mm
U2: IS61W204816BLL; TSOP-I-48_18.4x12mm_P0.5mm; Manufacturer Part IS61WV204816BLL-10TLI; LCSC Part Name IS61WV204816BLL 10TLI
U29: 74LVC1G07; SOT-23-5
U30: GD25Q32JVSS; SOIC-8_5.3x5.3mm_P1.27mm
Y1: 24MHz; Crystal_SMD_2016-4Pin_2.0x1.6mm

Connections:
+3.3V: C3.1, C4.1, C5.1, C6.1, C7.1, C8.1, C9.1, C10.1, C11.1, C17.1, C18.1, C19.1, C144.1, C145.1, C146.1, C147.1, R2.2, R65.1, U1.6 (VBAT), U1.13 (VDD), U1.31 (VDD), U1.47 (VDD), U1.64 (VDD), U1.79 (VDD), U1.95 (VDD), U1.111 (VDD), U1.128 (VDD), U2.12 (VDD), U2.36 (VDD), U29.5 (VCC), U30.8 (VCC); also elsewhere on the board
+3.3VA: C12.1, C13.1, U1.45 (VDDA); also elsewhere on the board
/CH1,2/Ctrl1: U1.4 (PE5); also elsewhere on the board
/CH1,2/Ctrl2: U1.5 (PE6); also elsewhere on the board
/CH3,4/Ctrl3: U1.7 (PC13); also elsewhere on the board
/CH3,4/Ctrl4: U1.8 (PC14); also elsewhere on the board
/MCU/A0: U1.18 (PF10), U2.5 (A0)
/MCU/A1: U1.15 (PF7), U2.4 (A1)
/MCU/A2: U1.26 (PF2), U2.3 (A2)
/MCU/A3: U1.10 (PF3), U2.2 (A3)
/MCU/A4: U1.11 (PF4), U2.1 (A4)
/MCU/A5: U1.14 (PF5), U2.48 (A5)
/MCU/A6: U1.49 (PF12), U2.47 (A6)
/MCU/A7: U1.50 (PF13), U2.46 (A7)
/MCU/A8: U1.51 (PF14), U2.45 (A8)
/MCU/A9: U1.52 (PF15), U2.30 (A9)
/MCU/A10: U1.82 (PG0), U2.29 (A10)
/MCU/A11: U1.83 (PG1), U2.28 (A11)
/MCU/A12: U1.84 (PG2), U2.27 (A12)
/MCU/A13: U1.85 (PG3), U2.26 (A13)
/MCU/A14: U1.86 (PG4), U2.25 (A14)
/MCU/A15: U1.103 (PG5), U2.24 (A15)
/MCU/A16: U1.73 (PD11), U2.23 (A16)
/MCU/A17: U1.74 (PD12), U2.22 (A17)
/MCU/A18: U1.75 (PD13), U2.21 (A18)
/MCU/A19: U1.2 (PE3), U2.20 (A19)
/MCU/A20: U1.3 (PE4), U2.31 (A20)
/MCU/CH1+: U1.22 (PC0); also elsewhere on the board
/MCU/CH1-: U1.23 (PC1); also elsewhere on the board
/MCU/CH2+: U1.24 (PC2); also elsewhere on the board
/MCU/CH2-: U1.25 (PC3); also elsewhere on the board
/MCU/CH3+: U1.27 (PA0); also elsewhere on the board
/MCU/CH3-: U1.28 (PA1); also elsewhere on the board
/MCU/CH4+: U1.38 (PC5); also elsewhere on the board
/MCU/CH4-: U1.41 (PB2); also elsewhere on the board
/MCU/CTrig0: U1.121 (PB6); also elsewhere on the board
/MCU/CTrig1: U1.122 (PB7); also elsewhere on the board
/MCU/Flash_CLK: U1.32 (PA3), U30.6 (CLK)
/MCU/Flash_IO0: U1.40 (PB1), U30.5 (DI/IO_{0})
/MCU/Flash_IO1: U1.39 (PB0), U30.2 (DO/IO_{1})
/MCU/Flash_IO2: U1.36 (PA7), U30.3 (~WP/IO_{2})
/MCU/Flash_IO3: U1.35 (PA6), U30.7 (~HOLD/~RESET/IO_{3})
/MCU/Flash_~CS: U1.29 (PA2), U30.1 (~CS)
/MCU/IO0: U1.76 (PD14), U2.8 (I/O0)
/MCU/IO1: U1.77 (PD15), U2.9 (I/O1)
/MCU/IO2: U1.108 (PD0), U2.10 (I/O2)
/MCU/IO3: U1.109 (PD1), U2.11 (I/O3)
/MCU/IO4: U1.53 (PE7), U2.14 (I/O4)
/MCU/IO5: U1.54 (PE8), U2.15 (I/O5)
/MCU/IO6: U1.55 (PE9), U2.16 (I/O6)
/MCU/IO7: U1.56 (PE10), U2.17 (I/O7)
/MCU/IO8: U1.57 (PE11), U2.32 (I/O8)
/MCU/IO9: U1.58 (PE12), U2.33 (I/O9)
/MCU/IO10: U1.59 (PE13), U2.34 (I/O10)
/MCU/IO11: U1.60 (PE14), U2.35 (I/O11)
/MCU/IO12: U1.61 (PE15), U2.38 (I/O12)
/MCU/IO13: U1.70 (PD8), U2.39 (I/O13)
/MCU/IO14: U1.71 (PD9), U2.40 (I/O14)
/MCU/IO15: U1.72 (PD10), U2.41 (I/O15)
/MCU/NRST: C16.1, R2.1, SW1.2 (B), U1.21 (PG10)
/MCU/OSC_IN: C1.1, U1.19 (RCC_OSC_IN), Y1.1
/MCU/OSC_OUT: C2.1, U1.20 (RCC_OSC_OUT), Y1.3
/MCU/SWCLK: J1.1, U1.98 (PA14)
/MCU/SWDIO: J1.2, U1.96 (PA13)
/MCU/TRIG: U1.65 (PB11); also elsewhere on the board
/MCU/USART_TX: U1.90 (PA9), U29.2
/MCU/V_{REF_OUT}: U1.43 (VREFBUF_OUT1), U1.44 (VREFBUF_OUT2); also elsewhere on the board
/MCU/~CS: U1.117 (PD7), U2.7 (CS#)
/MCU/~LB: U1.125 (PE0), U2.42 (LB#)
/MCU/~OE: U1.114 (PD4), U2.44 (OE#)
/MCU/~UB: U1.126 (PE1), U2.43 (UB#)
/MCU/~WE: U1.115 (PD5), U2.18 (WE#)
/U.RXD: R65.2, U1.91 (PA10); also elsewhere on the board
/U.TXD: U29.4; also elsewhere on the board
/USB.USB_Check: U1.89 (PA8); also elsewhere on the board
/USB.USB_D+: U1.93 (PA12); also elsewhere on the board
/USB.USB_D-: U1.92 (PA11); also elsewhere on the board
GND: C1.2, C2.2, C3.2, C4.2, C5.2, C6.2, C7.2, C8.2, C9.2, C10.2, C11.2, C12.2, C13.2, C16.2, C17.2, C18.2, C19.2, C144.2, C145.2, C146.2, C147.2, J1.3, R1.2, SW1.1 (A), U1.12 (VSS), U1.30 (VSS), U1.42 (VSSA), U1.46 (VSS), U1.63 (VSS), U1.78 (VSS), U1.94 (VSS), U1.110 (VSS), U1.127 (VSS), U2.13 (VSS), U2.37 (VSS), U29.3 (GND), U30.4 (GND), Y1.2 (G), Y1.4 (G); also elsewhere on the board
unnamed: R1.1, U1.123 (PB8)

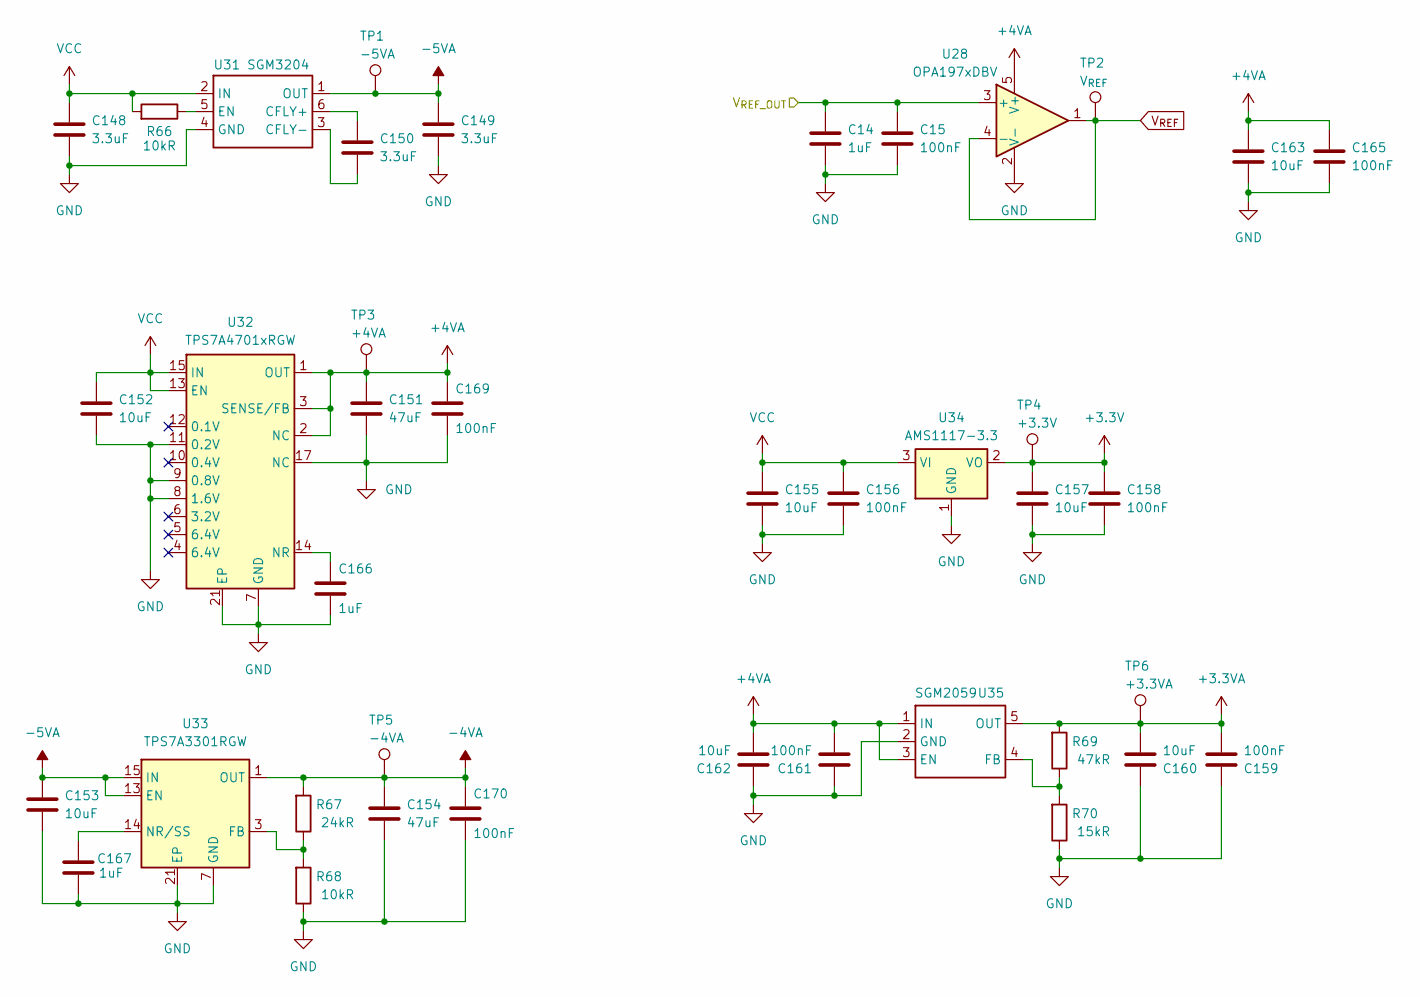
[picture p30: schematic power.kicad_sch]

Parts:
C14, C166, C167: 1uF; C_0603_1608Metric
C15, C156, C158, C159, C161, C165, C169, C170: 100nF; C_0603_1608Metric
C148, C149, C150: 3.3uF; C_0603_1608Metric
C151, C154: 47uF; C_1206_3216Metric
C152, C153, C155, C157, C160, C162, C163: 10uF; C_0603_1608Metric
R66, R68: 10kR; R_0603_1608Metric
R67: 24kR; R_0603_1608Metric
R69: 47kR; R_0603_1608Metric
R70: 15kR; R_0603_1608Metric
TP1: -5VA; TestPoint_Pad_D1.0mm
TP2: V_{REF}; TestPoint_Pad_D1.0mm
TP3: +4VA; TestPoint_Pad_D1.0mm
TP4: +3.3V; TestPoint_Pad_D1.0mm
TP5: -4VA; TestPoint_Pad_D1.0mm
TP6: +3.3VA; TestPoint_Pad_D1.0mm
U28: OPA197xDBV; SOT-23-5
U31: SGM3204; SOT-23-6; Manufacturer Part SGM3204YN6G/TR; LCSC Part Name SGM3204YN6G/TR
U32: TPS7A4701xRGW; Texas_RGW0020A_VQFN-20-1EP_5x5mm_P0.65mm_EP3.15x3.15mm_Ther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
U33: TPS7A3301RGW; Texas_RGW0020A_VQFN-20-1EP_5x5mm_P0.65mm_EP3.15x3.15mm_Ther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
U34: AMS1117-3.3; SOT-223-3_TabPin2
U35: SGM2059; SOT-23-5; Manufacturer Part SGM2059-ADJXN5G/TR; LCSC Part Name 300mA，低输入电压、超低噪声、高电源抑制比线性稳压器

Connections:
+3.3V: C157.1, C158.1, TP4.1 (1_1), U34.2 (VO); also elsewhere on the board
+3.3VA: C159.2, C160.2, R69.2, TP6.1 (1_1), U35.5 (OUT); also elsewhere on the board
+4VA: C151.1, C161.2, C162.2, C163.1, C165.2, C169.2, TP3.1 (1_1), U28.5 (V+), U32.1 (OUT), U32.2 (NC), U32.3 (SENSE/FB), U32.20 (OUT), U35.1 (IN), U35.3 (EN); also elsewhere on the board
-4VA: C154.1, C170.2, R67.2, TP5.1 (1_1), U33.1 (OUT), U33.20 (OUT); also elsewhere on the board
-5VA: C149.1, C153.1, TP1.1 (1_1), U31.1 (OUT), U33.13 (EN), U33.15 (IN), U33.16 (IN)
/MCU/V_{REF_OUT}: C14.1, C15.1, U28.3 (+); also elsewhere on the board
GND: C14.2, C15.2, C148.2, C149.2, C151.2, C152.2, C153.2, C154.2, C155.2, C156.2, C157.2, C158.2, C159.1, C160.1, C161.1, C162.1, C163.2, C165.1, C166.1, C167.1, C169.1, C170.1, R68.1, R70.1, U28.2 (V-), U31.4 (GND), U32.7 (GND), U32.8 (1.6V), U32.9 (0.8V), U32.11 (0.2V), U32.17 (NC), U32.18 (NC), U32.19 (NC), U32.21 (EP), U33.7 (GND), U33.21 (EP), U34.1 (GND), U35.2 (GND); also elsewhere on the board
unnamed: C150.1, U31.6 (CFLY+)
unnamed: C150.2, U31.3 (CFLY-)
unnamed: R66.1, U31.5 (EN)
unnamed: C166.2, U32.14 (NR)
unnamed: R67.1, R68.2, U33.3 (FB)
unnamed: C167.2, U33.14 (NR/SS)
unnamed: R69.1, R70.2, U35.4 (FB)
VCC: C148.1, C152.1, C155.1, C156.1, R66.2, U31.2 (IN), U32.13 (EN), U32.15 (IN), U32.16 (IN), U34.3 (VI); also elsewhere on the board
V_{REF}: TP2.1 (1_1), U28.1, U28.4 (-); also elsewhere on the board

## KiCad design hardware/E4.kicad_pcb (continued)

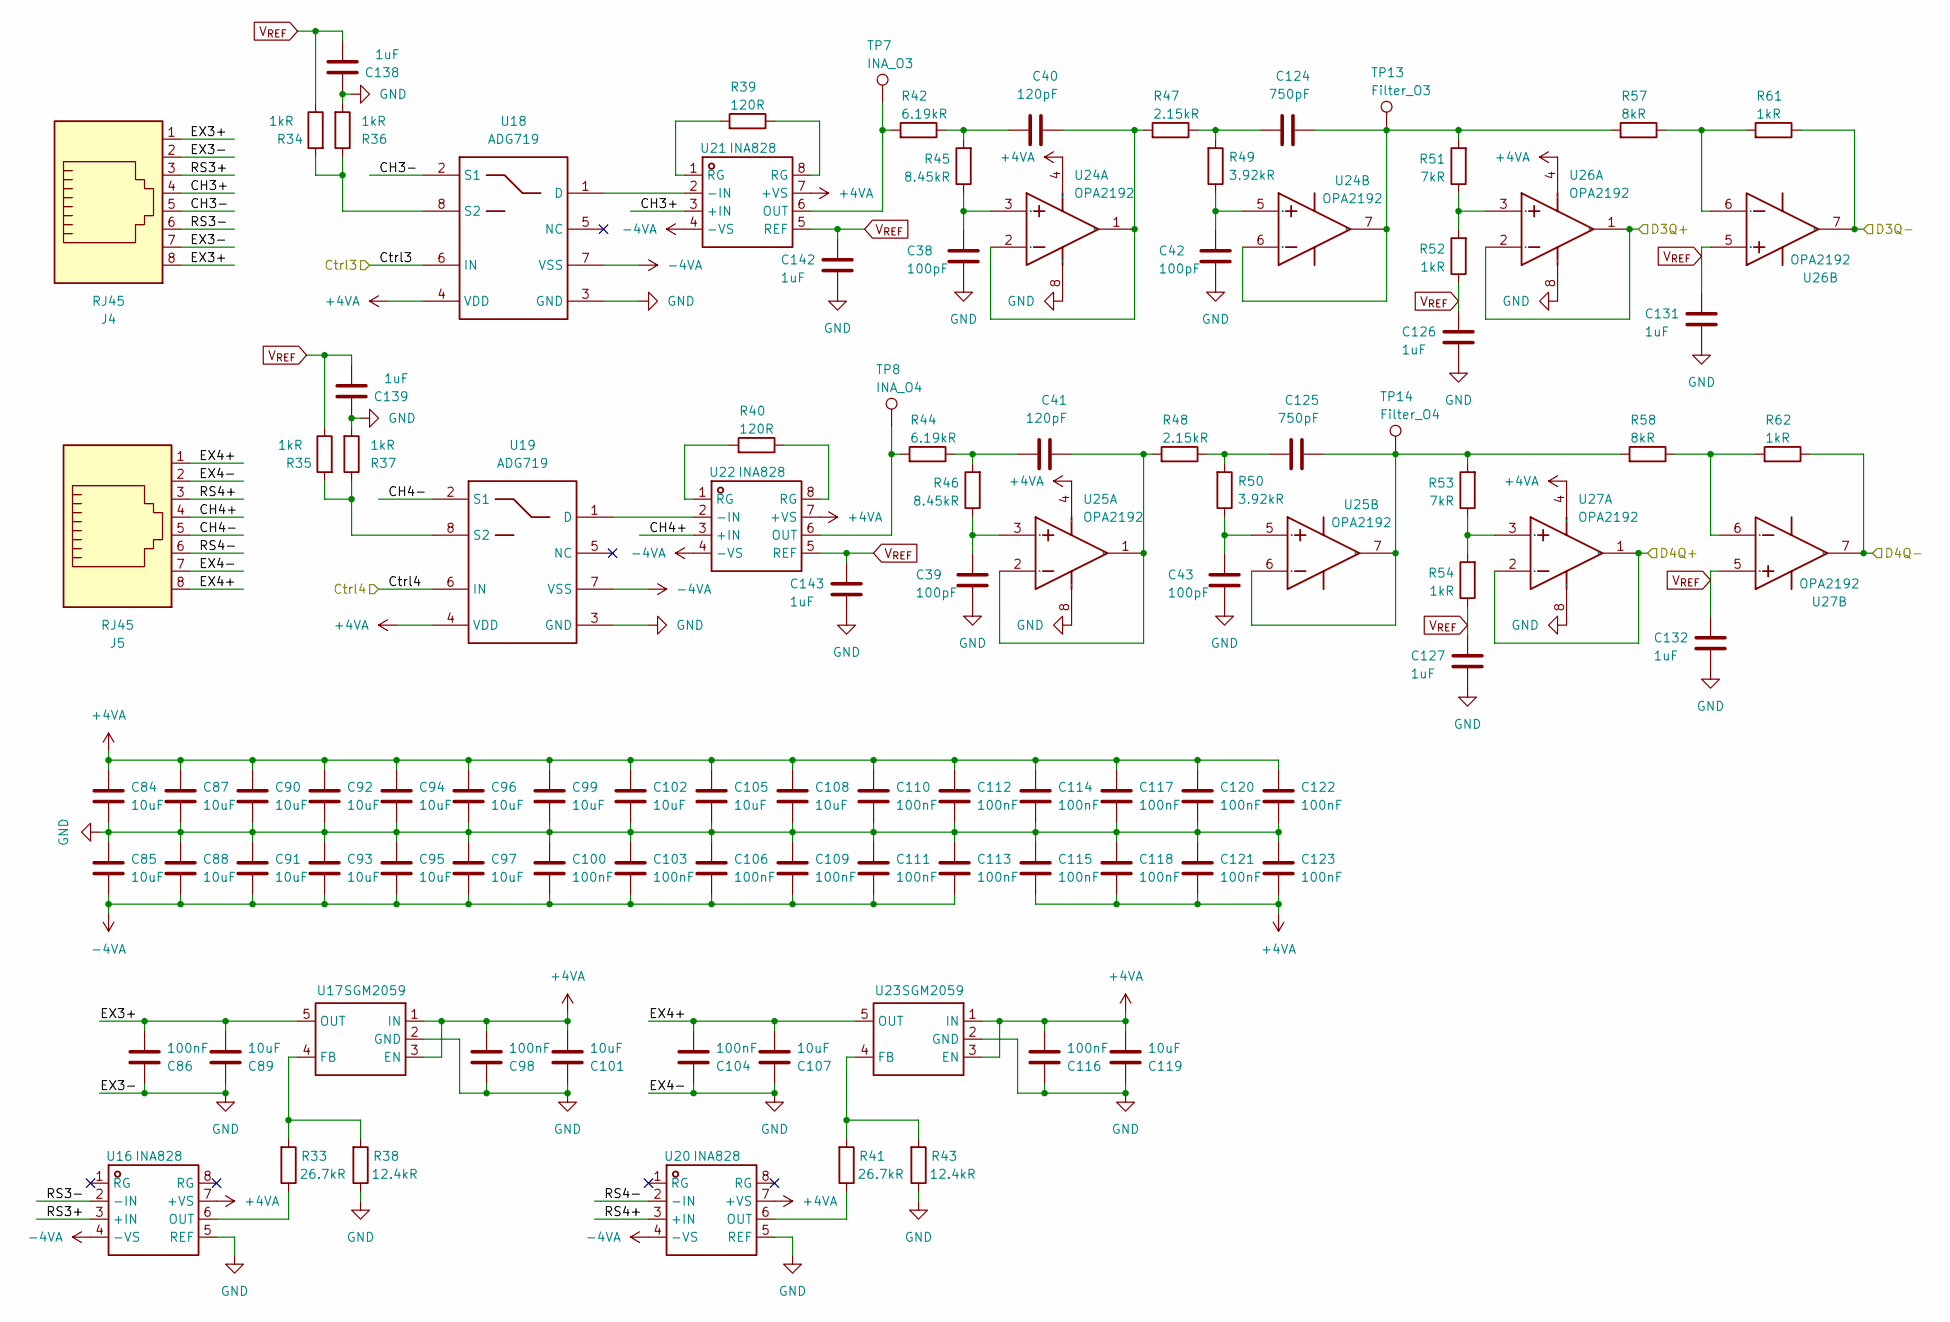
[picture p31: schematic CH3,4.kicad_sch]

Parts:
C38, C39, C42, C43: 100pF; C_0603_1608Metric
C40, C41: 120pF; C_0603_1608Metric
C84, C85, C87, C88, C89, C90, C91, C92, C93, C94, C95, C96, C97, C99, C101, C102, C105, C107, C108, C119: 10uF; C_0603_1608Metric
C86, C98, C100, C103, C104, C106, C109, C110, C111, C112, C113, C114, C115, C116, C117, C118, C120, C121, C122, C123: 100nF; C_0603_1608Metric
C124, C125: 750pF; C_0603_1608Metric
C126, C127, C131, C132, C138, C139, C142, C143: 1uF; C_0603_1608Metric
J4, J5: RJ45; RJ45_Amphenol_54602-x08_Horizontal
R33, R41: 26.7kR; R_0603_1608Metric
R34, R35, R36, R37, R52, R54, R61, R62: 1kR; R_0603_1608Metric
R38, R43: 12.4kR; R_0603_1608Metric
R39, R40: 120R; R_0603_1608Metric
R42, R44: 6.19kR; R_0603_1608Metric
R45, R46: 8.45kR; R_0603_1608Metric
R47, R48: 2.15kR; R_0603_1608Metric
R49, R50: 3.92kR; R_0603_1608Metric
R51, R53: 7kR; R_0603_1608Metric
R57, R58: 8kR; R_0603_1608Metric
TP7: INA_O3; TestPoint_Pad_D1.0mm
TP8: INA_O4; TestPoint_Pad_D1.0mm
TP13: Filter_O3; TestPoint_Pad_D1.0mm
TP14: Filter_O4; TestPoint_Pad_D1.0mm
U16, U20, U21, U22: INA828; SOIC-8_3.9x4.9mm_P1.27mm; Manufacturer Part INA828IDR; LCSC Part Name INA828IDR
U17, U23: SGM2059; SOT-23-5; Manufacturer Part SGM2059-ADJXN5G/TR; LCSC Part Name 300mA，低输入电压、超低噪声、高电源抑制比线性稳压器
U18, U19: ADG719; SOT-23-8; Manufacturer Part ADG619BRTZ-REEL7; LCSC Part Name CMOS单刀双掷开关
U24, U25, U26, U27: OPA2192; SOIC-8_3.9x4.9mm_P1.27mm; Manufacturer Part OPA2192IDR; LCSC Part Name OPA2192IDR

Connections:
+4VA: C84.1, C87.1, C90.1, C92.1, C94.1, C96.1, C98.2, C99.1, C101.2, C102.1, C105.1, C108.1, C110.2, C112.2, C114.2, C115.1, C116.2, C117.2, C118.1, C119.2, C120.2, C121.1, C122.2, C123.1, U16.7 (+VS), U17.1 (IN), U17.3 (EN), U18.4 (VDD), U19.4 (VDD), U20.7 (+VS), U21.7 (+VS), U22.7 (+VS), U23.1 (IN), U23.3 (EN), U24.4 (VSS), U25.4 (VSS), U26.4 (VSS), U27.4 (VSS); also elsewhere on the board
-4VA: C85.2, C88.2, C91.2, C93.2, C95.2, C97.2, C100.1, C103.1, C106.1, C109.1, C111.1, C113.1, U16.4 (-VS), U18.7 (VSS), U19.7 (VSS), U20.4 (-VS), U21.4 (-VS), U22.4 (-VS); also elsewhere on the board
/CH3,4/CH3+: J4.4, U21.3 (+IN)
/CH3,4/CH3-: J4.5, U18.2 (S1)
/CH3,4/CH4+: J5.4, U22.3 (+IN)
/CH3,4/CH4-: J5.5, U19.2 (S1)
/CH3,4/Ctrl3: U18.6 (IN); also elsewhere on the board
/CH3,4/Ctrl4: U19.6 (IN); also elsewhere on the board
/CH3,4/D3Q+: U26.1 (VOUTA), U26.2 (VINA-); also elsewhere on the board
/CH3,4/D3Q-: R61.1, U26.7 (VOUTB); also elsewhere on the board
/CH3,4/D4Q+: U27.1 (VOUTA), U27.2 (VINA-); also elsewhere on the board
/CH3,4/D4Q-: R62.1, U27.7 (VOUTB); also elsewhere on the board
/CH3,4/EX3+: C86.2, C89.2, J4.1, J4.8, U17.5 (OUT)
/CH3,4/EX4+: C104.2, C107.2, J5.1, J5.8, U23.5 (OUT)
/CH3,4/RS3+: J4.3, U16.3 (+IN)
/CH3,4/RS3-: J4.6, U16.2 (-IN)
/CH3,4/RS4+: J5.3, U20.3 (+IN)
/CH3,4/RS4-: J5.6, U20.2 (-IN)
GND: C38.2, C39.2, C42.2, C43.2, C84.2, C85.1, C86.1, C87.2, C88.1, C89.1, C90.2, C91.1, C92.2, C93.1, C94.2, C95.1, C96.2, C97.1, C98.1, C99.2, C100.2, C101.1, C102.2, C103.2, C104.1, C105.2, C106.2, C107.1, C108.2, C109.2, C110.1, C111.2, C112.1, C113.2, C114.1, C115.2, C116.1, C117.1, C118.2, C119.1, C120.1, C121.2, C122.1, C123.2, C126.2, C127.2, C131.2, C132.2, C138.1, C139.1, C142.2, C143.2, J4.2, J4.7, J5.2, J5.7, R36.2, R37.2, R38.1, R43.1, U16.5 (REF), U17.2 (GND), U18.3 (GND), U19.3 (GND), U20.5 (REF), U23.2 (GND), U24.8 (VDD), U25.8 (VDD), U26.8 (VDD), U27.8 (VDD); also elsewhere on the board
unnamed: C40.2, R42.1, R45.2
unnamed: C41.2, R44.1, R46.2
unnamed: C124.2, R47.1, R49.2
unnamed: C125.2, R48.1, R50.2
unnamed: R39.1, U21.8 (RG)
unnamed: R39.2, U21.1 (RG)
unnamed: R40.1, U22.8 (RG)
unnamed: R40.2, U22.1 (RG)
unnamed: R33.1, U16.6 (OUT)
unnamed: R33.2, R38.2, U17.4 (FB)
unnamed: U18.1 (D), U21.2 (-IN)
unnamed: R34.2, R36.1, U18.8 (S2)
unnamed: U19.1 (D), U22.2 (-IN)
unnamed: R35.2, R37.1, U19.8 (S2)
unnamed: R41.1, U20.6 (OUT)
unnamed: R42.2, TP7.1 (1_1), U21.6 (OUT)
unnamed: R44.2, TP8.1 (1_1), U22.6 (OUT)
unnamed: R41.2, R43.2, U23.4 (FB)
unnamed: C38.1, R45.1, U24.3 (VINA+)
unnamed: C40.1, R47.2, U24.1 (VOUTA), U24.2 (VINA-)
unnamed: C42.1, R49.1, U24.5 (VINB+)
unnamed: C124.1, R51.2, R57.2, TP13.1 (1_1), U24.6 (VINB-), U24.7 (VOUTB)
unnamed: C39.1, R46.1, U25.3 (VINA+)
unnamed: C41.1, R48.2, U25.1 (VOUTA), U25.2 (VINA-)
unnamed: C43.1, R50.1, U25.5 (VINB+)
unnamed: C125.1, R53.2, R58.2, TP14.1 (1_1), U25.6 (VINB-), U25.7 (VOUTB)
unnamed: R51.1, R52.2, U26.3 (VINA+)
unnamed: R57.1, R61.2, U26.6 (VINB-)
unnamed: R53.1, R54.2, U27.3 (VINA+)
unnamed: R58.1, R62.2, U27.6 (VINB-)
V_{REF}: C126.1, C127.1, C131.1, C132.1, C138.2, C139.2, C142.1, C143.1, R34.1, R35.1, R52.1, R54.1, U21.5 (REF), U22.5 (REF), U26.5 (VINB+), U27.5 (VINB+); also elsewhere on the board

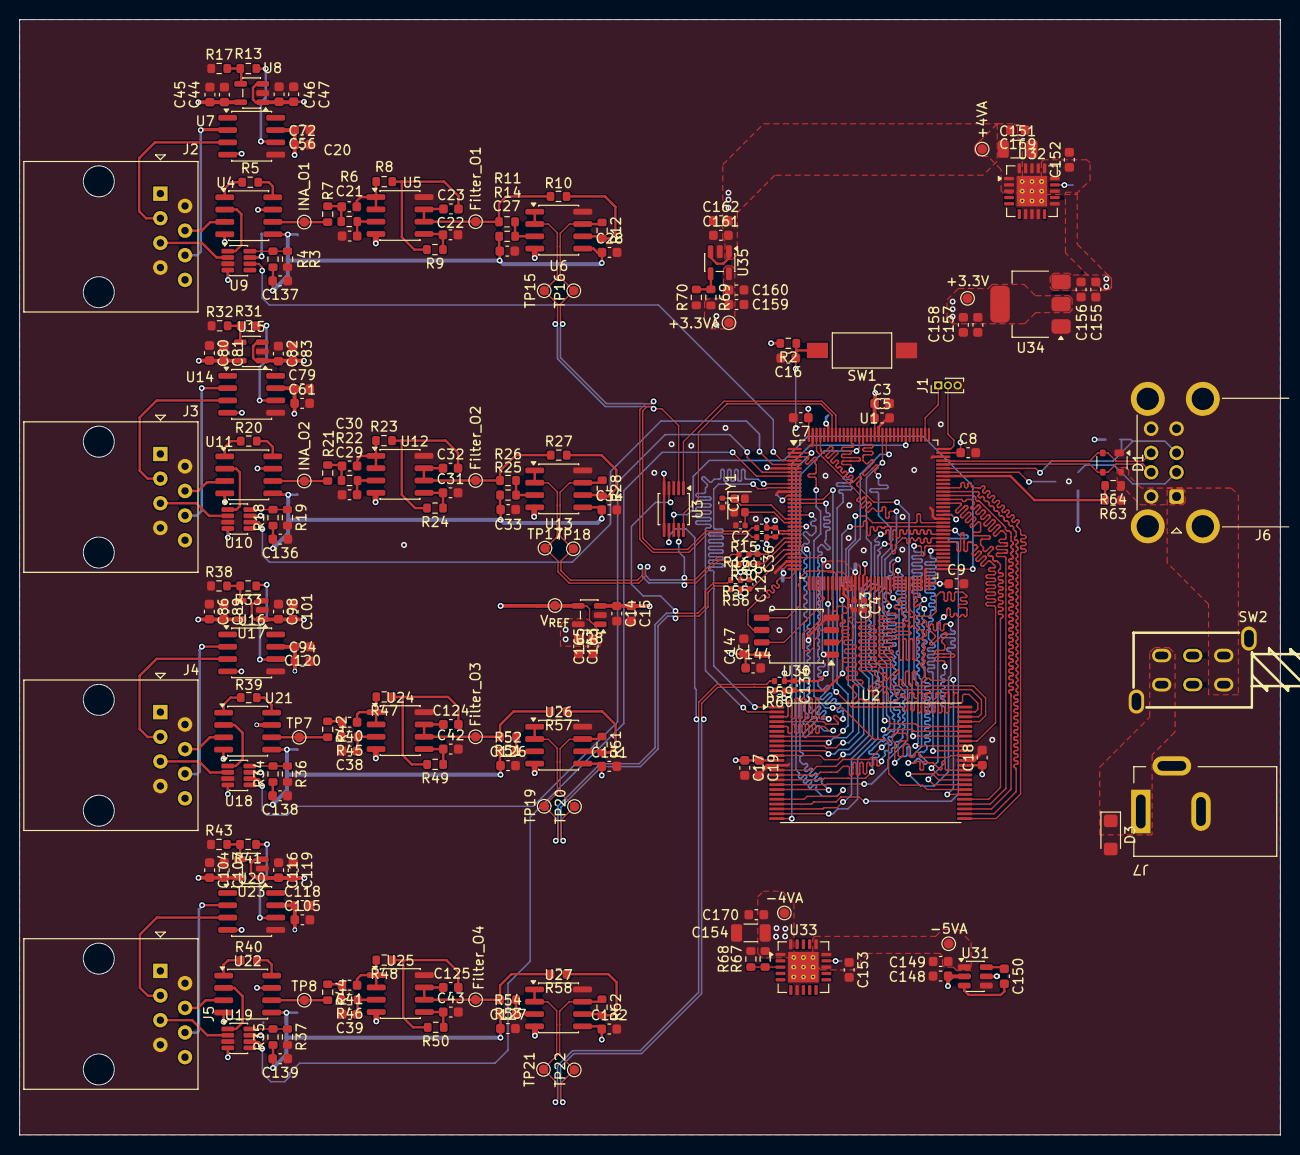
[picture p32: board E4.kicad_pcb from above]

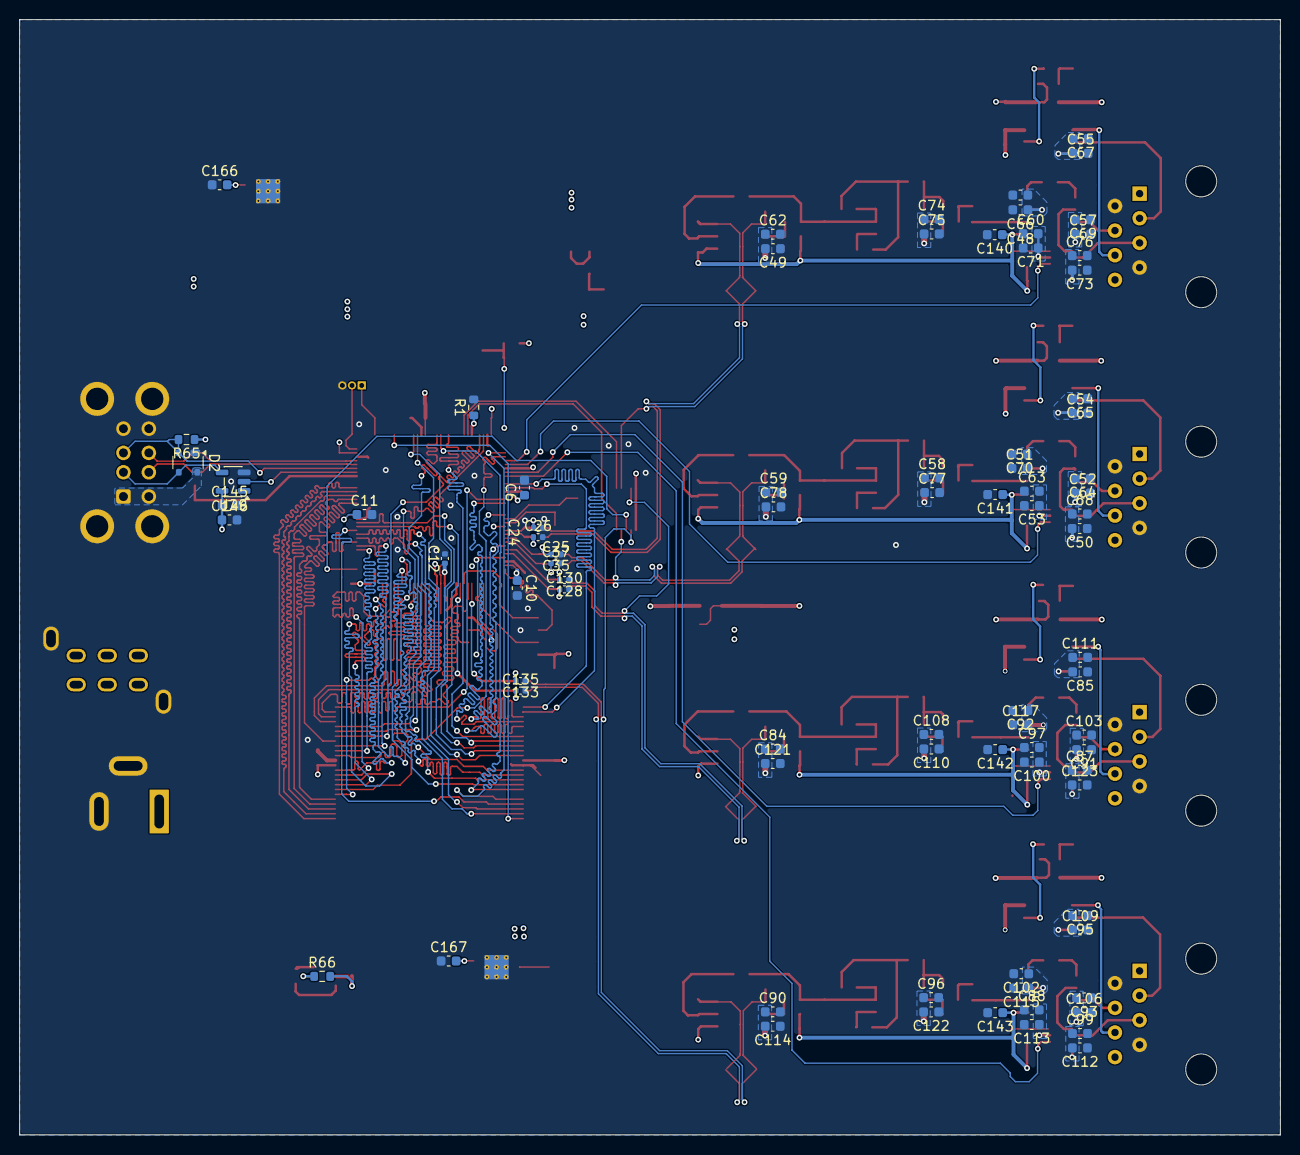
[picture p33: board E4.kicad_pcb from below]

Board: 4 copper layers, 130.0 x 115.0 mm, 308 parts (81 on the bottom side), 181 nets.

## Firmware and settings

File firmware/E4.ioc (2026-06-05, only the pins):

Mcu.UserName=STM32G473QETx
PA0.Signal=ADC1_IN1
PA1.Signal=ADC1_IN2
PA10.Signal=USART1_RX
PA11.Signal=USB_DM
PA12.Signal=USB_DP
PA13.Signal=SYS_JTMS-SWDIO
PA14.Signal=SYS_JTCK-SWCLK
PA2.Signal=QUADSPI1_BK1_NCS
PA3.Signal=QUADSPI1_CLK
PA6.Signal=QUADSPI1_BK1_IO3
PA7.Signal=QUADSPI1_BK1_IO2
PA8.GPIO_Label=USB_Check
PA8.Signal=GPXTI8
PA9.Signal=USART1_TX
PB0.Signal=QUADSPI1_BK1_IO1
PB1.Signal=QUADSPI1_BK1_IO0
PB11.Signal=COMP6_INP
PB2.Signal=ADC2_IN12
PB6.GPIO_Label=CTrig1
PB6.Signal=GPIO_Output
PB7.GPIO_Label=CTrig0
PB7.Signal=GPIO_Output
PC0.Signal=ADC2_IN6
PC1.Signal=ADC2_IN7
PC13.GPIO_Label=Ctrl3
PC13.Signal=GPIO_Output
PC14-OSC32_IN.GPIO_Label=Ctrl4
PC14-OSC32_IN.Signal=GPIO_Output
PC2.Signal=ADC1_IN8
PC3.Signal=ADC1_IN9
PC5.Signal=ADC2_IN11
PD0.Signal=FMC_D2_DA2
PD1.Signal=FMC_D3_DA3
PD10.Signal=FMC_D15_DA15
PD11.Signal=FMC_A16_CLE
PD12.Signal=FMC_A17_ALE
PD13.Signal=FMC_A18
PD14.Signal=FMC_D0_DA0
PD15.Signal=FMC_D1_DA1
PD4.Signal=FMC_NOE
PD5.Signal=FMC_NWE
PD7.Signal=FMC_NE1
PD8.Signal=FMC_D13_DA13
PD9.Signal=FMC_D14_DA14
PE10.Signal=FMC_D7_DA7
PE11.Signal=FMC_D8_DA8
PE12.Signal=FMC_D9_DA9
PE13.Signal=FMC_D10_DA10
PE14.Signal=FMC_D11_DA11
PE15.Signal=FMC_D12_DA12
PE3.Signal=FMC_A19
PE4.Signal=FMC_A20
PE5.GPIO_Label=Ctrl1
PE5.Signal=GPIO_Output
PE6.GPIO_Label=Ctrl2
PE6.Signal=GPIO_Output
PE7.Signal=FMC_D4_DA4
PE8.Signal=FMC_D5_DA5
PE9.Signal=FMC_D6_DA6
PF0-OSC_IN.Signal=RCC_OSC_IN
PF1-OSC_OUT.Signal=RCC_OSC_OUT
PF10.Signal=FMC_A0
PF12.Signal=FMC_A6
PF13.Signal=FMC_A7
PF14.Signal=FMC_A8
PF15.Signal=FMC_A9
PF2.Signal=FMC_A2
PF3.Signal=FMC_A3
PF4.Signal=FMC_A4
PF5.Signal=FMC_A5
PF7.Signal=FMC_A1
PG0.Signal=FMC_A10
PG1.Signal=FMC_A11
PG2.Signal=FMC_A12
PG3.Signal=FMC_A13
PG4.Signal=FMC_A14
PG5.Signal=FMC_A15

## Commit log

2026-05-26 创建仓库
2026-05-28 feat：绘制元件库
    [E4.kicad_pcb, E4.kicad_sch, MCU.kicad_sch]
2026-05-28 feat：MCU最小系统原理图设计；SRAM原理图设计
    [MCU.kicad_sch]
2026-05-28 feat：MCU引脚初步分配（ADC、QSPI、SRAM、电平触发、USB、USART、最小系统）
2026-05-29 docs：完成硬件架构文档
2026-05-29 docs：硬件设计文档-MCU最小系统
2026-06-01 feat：修复README显示问题
2026-06-01 docs：仪表放大器设计
2026-06-01 simulation：仪表放大器部分
2026-06-02 simulation：滤波器部分
2026-06-02 simulation：单端转差分部分
2026-06-02 docs：滤波器设计；差分转单端设计
2026-06-02 feat：仪表放大器、滤波器原理图
    [CH1,2.kicad_sch, E4.kicad_sch]
2026-06-02 feat：差分转单端原理图
2026-06-02 docs：更换仪表放大器-模拟开关选型
2026-06-02 feat：远程感测原理图；多路通道
    [CH3,4.kicad_sch, E4.kicad_sch]
2026-06-02 docs：补充原理图
2026-06-03 feat：输入滤波原理图
    [CH1,2.kicad_sch, CH3,4.kicad_sch, E4.kicad_sch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]
2026-06-03 feat：电平触发原理图
    [input_condition.kicad_sch]
2026-06-03 feat：QSPI原理图
    [MCU.kicad_sch]
2026-06-03 feat：电源原理图
    [E4.kicad_sch, MCU.kicad_sch, input_condition.kicad_sch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]
2026-06-03 docs：外部触发、存储扩展、电源设计；PCB布局布线指南
2026-06-04 feat：模拟前端布线，单片机/SRAM布线
    [CH1,2.kicad_sch, CH3,4.kicad_sch, E4.kicad_pcb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]
2026-06-04 feat：电源部分
    [CH1,2.kicad_sch, CH3,4.kicad_sch, E4.kicad_pcb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]
2026-06-04 feat：总体连接
    [CH1,2.kicad_sch, CH3,4.kicad_sch, E4.kicad_pcb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]
2026-06-04 feat：完成BOM表
    [1111E4-立创_20260604-立创_20260604.xls]
2026-06-04 feat：CubeMX配置
2026-06-04 docs：软件设计文档
2026-06-05 docs：报告整理
    [1111E4-立创_20260604-立创_20260604.csv, 1111E4-立创_20260604-立创_20260604.xls]
2026-06-05 feat：整理设计文件
    [1111E4-立创_20260604-立创_20260604.xls, E4.kicad_pcb, MCU.kicad_sch]
2026-06-05 simulation：整理设计文件
2026-10-26 修正动态标签地址
2026-10-26 修复 README 仓库结构渲染
